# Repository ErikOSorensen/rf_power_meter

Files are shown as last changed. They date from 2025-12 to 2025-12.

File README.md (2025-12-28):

# RF Power Meter

Dual-channel RF power meter using Raspberry Pi Pico with W5500 Ethernet, featuring SCPI control and mDNS discovery.

## Architecture Overview

```
┌─────────────────────────────────────────────────────────────────┐
│                         main.py                                  │
│                    (Application Controller)                      │
│  - Initializes all subsystems                                   │
│  - Runs async task scheduler                                    │
│  - Coordinates sensor reading, display, and network tasks       │
└─────────────────────────────────────────────────────────────────┘
         │              │              │              │
         ▼              ▼              ▼              ▼
┌─────────────┐ ┌─────────────┐ ┌─────────────┐ ┌─────────────┐
│   sensors/  │ │  display/   │ │  network/   │ │    scpi/    │
│             │ │             │ │             │ │             │
│ ADC reading │ │ OLED output │ │ Ethernet &  │ │  Command    │
│ EEPROM cal  │ │ Power bars  │ │ TCP server  │ │  parsing    │
└─────────────┘ └─────────────┘ └─────────────┘ └─────────────┘
```

## Key Features

- **EEPROM-based calibration**: Each sensor module stores its own calibration data in an onboard EEPROM. Calibration travels with the sensor, not the channel.
- **Frequency-dependent calibration**: Store separate offset/slope corrections for each calibration frequency.
- **Hot-swappable sensors**: Sensors are automatically detected at startup via I2C multiplexer.
- **SCPI control**: Standard SCPI commands over TCP port 5025.
- **mDNS discovery**: Find the meter as `rfmeter.local`.

## File Responsibilities

### Core

| File | Purpose |
|---|---|
| `main.py` | Application entry point. Initializes hardware, detects sensors, starts async tasks for sensor reading (50ms), display updates (200ms), TCP server, and mDNS. |
| `config.py` | Central configuration: GPIO pins, I2C addresses, multiplexer settings, network settings, instrument identity. |

### Sensors (`sensors/`)

| File | Purpose |
|---|---|
| `ads1115.py` | Low-level driver for ADS1115 16-bit ADC. Reads power sensor voltage. |
| `tca9548a.py` | TCA9548A I2C multiplexer driver. Selects which sensor's EEPROM is active. |
| `eeprom.py` | AT24C02 EEPROM driver. Reads/writes sensor type, serial number, and calibration data. |
| `calibration.py` | Calibration management. Detects sensors via EEPROM, manages per-frequency calibration, handles voltage-to-dBm conversion. |
| `power_sensor.py` | High-level power measurement. `PowerChannel` handles per-channel reading and averaging. `PowerMeter` manages both channels. |

### Display (`display/`)

| File | Purpose |
|---|---|
| `ssd1306.py` | Low-level driver for SSD1306 OLED displays. |
| `power_display.py` | Power meter UI rendering. Shows power reading, sensor type, bar graph, and IP address. |

### Network (`network/`)

| File | Purpose |
|---|---|
| `w5500.py` | W5500 Ethernet initialization. Configures SPI, handles DHCP. |
| `tcp_server.py` | Async TCP server on port 5025 (SCPI standard). |
| `mdns.py` | Multicast DNS responder. Announces `rfmeter.local`. |

### SCPI (`scpi/`)

| File | Purpose |
|---|---|
| `parser.py` | SCPI command parser. Handles short/long form matching. |
| `commands.py` | SCPI command implementations. |

## Hardware Design

### System Block Diagram

```
                                    ┌─────────────────────────────────┐
                                    │         Main Unit (Pico)        │
┌──────────────┐                    │                                 │
│ Sensor 1     │    Ethernet        │  ┌─────────┐    ┌──────────┐   │
│ ┌─────────┐  │    Cable           │  │TCA9548A │    │ ADS1115  │   │
│ │ RF Det  ├──┼────────────────────┼──┤ I2C Mux ├────┤ ADC #1   │   │
│ │ AD8307  │  │    (Power,I2C,     │  │  0x70   │    │  0x48    │   │
│ └─────────┘  │     Analog)        │  └────┬────┘    └──────────┘   │
│ ┌─────────┐  │                    │       │                        │
│ │ EEPROM  ├──┼────────────────────┼───────┘         ┌──────────┐   │
│ │ AT24C02 │  │                    │  ┌─────────┐    │ ADS1115  │   │
│ │  0x50   │  │                    │  │TCA9548A ├────┤ ADC #2   │   │
│ └─────────┘  │                    │  │ (ch 1)  │    │  0x49    │   │
└──────────────┘                    │  └─────────┘    └──────────┘   │
                                    │                                 │
┌──────────────┐                    │  ┌─────────┐    ┌──────────┐   │
│ Sensor 2     │    Ethernet        │  │TCA9548A │    │  OLED    │   │
│ ┌─────────┐  │    Cable           │  │ (ch 0)  │    │  0x3C    │   │
│ │ RF Det  ├──┼────────────────────┼──┴─────────┘    └──────────┘   │
│ │ AD8317  │  │                    │                                 │
│ └─────────┘  │                    │                 ┌──────────┐   │
│ ┌─────────┐  │                    │                 │  OLED    │   │
│ │ EEPROM  ├──┼────────────────────┼─────────────────┤  0x3D    │   │
│ │ AT24C02 │  │                    │                 └──────────┘   │
│ │  0x50   │  │                    │                                 │
│ └─────────┘  │                    │                 ┌──────────┐   │
└──────────────┘                    │                 │  W5500   │   │
                                    │                 │ Ethernet │   │
                                    │                 └──────────┘   │
                                    └─────────────────────────────────┘
```

### Ethernet Cable Pinout (T-568B)

Sensors connect to the main unit via standard Ethernet cables. This provides a convenient, shielded connection with enough conductors for power, I2C, and analog signals.

| Pin | Wire Color | Function | Notes |
|-----|---|---|---|
| 1 | Orange/White | 3.3V | For EEPROM and 3.3V sensors |
| 2 | Orange | GND | Power ground (shared with 5V return) |
| 3 | Green/White | I2C SDA | To TCA9548A mux |
| 4 | Blue | Analog Output | To ADS1115 input |
| 5 | Blue/White | Analog GND | ADC reference ground |
| 6 | Green | I2C SCL | To TCA9548A mux |
| 7 | Brown/White | 5V | For 5V sensors (AD8317, AD8318) |
| 8 | Brown | Presence Detect | Directly tied to 3.3V on sensor module |

**Power Supply Notes:**
- The EEPROM (AT24C02) always runs on 3.3V
- 3.3V sensors (AD8307, LTC5582): Connect RF detector VCC to pin 1
- 5V sensors (AD8317, AD8318): Connect RF detector VCC to pin 7
- Main unit must provide both 3.3V and 5V rails

**Hot-Swap Detection:**
- Pin 8 is directly connected to 3.3V on each sensor module
- Main unit has internal pull-down on presence detect GPIOs
- When sensor is connected: GPIO reads HIGH (3.3V)
- When sensor is disconnected: GPIO reads LOW (pulled down)
- Rising/falling edge interrupts trigger sensor re-detection

### Main Unit I2C Bus

All I2C devices share a single bus:

| Device | Address | Function |
|---|---|---|
| TCA9548A | 0x70 | I2C multiplexer for sensor EEPROMs |
| ADS1115 #1 | 0x48 | ADC for channel 1 (ADDR→GND) |
| ADS1115 #2 | 0x49 | ADC for channel 2 (ADDR→VDD) |
| OLED #1 | 0x3C | Display for channel 1 |
| OLED #2 | 0x3D | Display for channel 2 |

**Multiplexer Channel Mapping:**
- TCA9548A Channel 0 → Sensor 1 EEPROM
- TCA9548A Channel 1 → Sensor 2 EEPROM

All sensor EEPROMs use address 0x50. The multiplexer isolates them so only one is active at a time.

**Why Two ADS1115 ADCs?**

Each ADS1115 supports 4 single-ended or 2 differential inputs, so a single chip could theoretically handle both channels. However, this design uses one ADC per channel for the following reasons:

1. **Simultaneous sampling**: Both channels can be read at the exact same time with no phase skew or multiplexing delays. This matters when comparing signals between ports or measuring relative power.

2. **Differential measurement**: Each channel uses differential inputs (AIN0-AIN1) with a dedicated analog ground reference per sensor. This provides better noise rejection than single-ended measurements over the Ethernet cable.

3. **Simplicity**: No ADC channel switching logic is needed. Each `PowerChannel` object owns its ADC, making the software straightforward.

4. **Minimal cost impact**: ADS1115 chips are inexpensive (~$1-2), so the added hardware cost is negligible compared to the software complexity savings.

A single-ADC design would require sequential readings with mux switching, introducing timing artifacts when comparing channels.

### Pico Pin Assignments

| Function | Pico Pin | Notes |
|---|---|---|
| I2C SDA | GP0 | I2C0 |
| I2C SCL | GP1 | I2C0 |
| Sensor 1 Detect | GP2 | Pull-down, IRQ on edge |
| Sensor 2 Detect | GP3 | Pull-down, IRQ on edge |
| TCA9548A Reset | GP4 | Active low, external pull-up |
| W5500 SPI MISO | GP16 | SPI0 |
| W5500 CS | GP17 | |
| W5500 SPI SCK | GP18 | SPI0 |
| W5500 SPI MOSI | GP19 | SPI0 |
| W5500 RST | GP20 | |

### Sensor Module Schematic

Each sensor module contains an RF detector chip and an EEPROM. The EEPROM always uses 3.3V, while the RF detector can use either 3.3V or 5V depending on the chip.

**3.3V Sensor (AD8307, LTC5582):**
```
                    ┌─────────────────────────────────────────┐
                    │         Sensor Module (3.3V)            │
   RJ45             │                                         │
  ┌─────┐           │  ┌─────────────┐      ┌─────────────┐  │
  │1 3V3├───┬───────┼──┤ VCC         ├──────┤ VCC         │  │
  │2 GND├───┼───────┼──┤         GND ├──────┤         GND │  │
  │3 SDA├───┼───────┼──┤ SDA  EEPROM │      │ RF Detector │  │
  │4 OUT│◄──┼───────┼──┤     AT24C02 │      │   AD8307    ├──┼── RF IN
  │5 AGND├──┼───────┼──┤ SCL   0x50  │      │             │  │   (SMA)
  │6 SCL├───┼───────┼──┤             │      │         OUT ├──┼─► Pin 4
  │7 5V │   │       │  └─────────────┘      └─────────────┘  │
  │8 DET├───┘       │           (directly tied to 3.3V)      │
  └─────┘           └─────────────────────────────────────────┘
```

**5V Sensor (AD8317, AD8318):**
```
                    ┌─────────────────────────────────────────┐
                    │          Sensor Module (5V)             │
   RJ45             │                                         │
  ┌─────┐           │  ┌─────────────┐      ┌─────────────┐  │
  │1 3V3├───┬───────┼──┤ VCC         │      │         VCC ├──┼─── Pin 7 (5V)
  │2 GND├───┼───────┼──┤         GND ├──────┤         GND │  │
  │3 SDA├───┼───────┼──┤ SDA  EEPROM │      │ RF Detector │  │
  │4 OUT│◄──┼───────┼──┤     AT24C02 │      │   AD8318    ├──┼── RF IN
  │5 AGND├──┼───────┼──┤ SCL   0x50  │      │             │  │   (SMA)
  │6 SCL├───┼───────┼──┤             │      │         OUT ├──┼─► Pin 4
  │7 5V ├───┼───────┼──┼─────────────┼──────┤             │  │
  │8 DET├───┘       │  └─────────────┘      └─────────────┘  │
  └─────┘           │           (directly tied to 3.3V)      │
                    └─────────────────────────────────────────┘
```

**Component List (per sensor module):**
- RF detector IC (AD8307, AD8317, AD8318, LTC5582, etc.)
- AT24C02 EEPROM (256 bytes, I2C address 0x50)
- RJ45 jack
- SMA connector for RF input
- Decoupling capacitors (100nF on each power rail)
- I2C pull-up resistors (2× 4.7kΩ)
- ESD protection (1× ESDAVLC6-2BLY for I2C lines)
- RF detector support components (per datasheet)

**Sensor Supply Voltage Reference:**

| Sensor | Supply | Connect VCC to |
|---|---|---|
| AD8307 | 2.7V - 5.5V | Pin 1 (3.3V) or Pin 7 (5V) |
| AD8317 | 3.0V - 5.5V | Pin 7 (5V) recommended |
| AD8318 | 4.5V - 5.5V | Pin 7 (5V) required |
| LTC5582 | 3.0V - 3.6V | Pin 1 (3.3V) only |

### Main Unit Schematic

The main unit requires both 3.3V (from Pico) and 5V (external) power supplies.

```
  5V DC ────┬──────────────────────────────────────────────────► To RJ45 Pin 7
            │
            │    Raspberry Pi Pico
            │   ┌─────────────────┐
            │   │                 │
     ┌──────┼───┤ GP0 (I2C0 SDA)  │
     │    ┌─┼───┤ GP1 (I2C0 SCL)  │
     │    │ │   │ GP2 (DET1)      ├◄───────────────────────────── Sensor 1 Detect
     │    │ │   │ GP3 (DET2)      ├◄───────────────────────────── Sensor 2 Detect
     │    │ │   │ GP4 (MUX RST)   ├───────────────────┐
     │    │ │   │                 │                   │  TCA9548A RESET
     │    │ │   │ GP16 (SPI MISO) ├────────┐
     │    │ │   │ GP17 (SPI CS)   ├───────┐│
     │    │ │   │ GP18 (SPI SCK)  ├──────┐││
     │    │ │   │ GP19 (SPI MOSI) ├─────┐│││
     │    │ │   │ GP20 (RST)      ├────┐││││
     │    │ │   │                 │    │││││
     │    │ │   │ VSYS ◄──────────┼────┼┼┼┼┼──── 5V DC (powers Pico)
     │    │ │   │ 3V3  ───────────┼─┐  │││││
     │    │ │   │ GND             ├─┼──┼┼┼┼┼─── GND
     │    │ │   └─────────────────┘ │  │││││
     │    │ │                       │  │││││
     │    │ │                       │  │││││    ┌────────────────┐
     │    │ │   ┌───────────────────┼──┼┼┼┼┘    │     W5500      │
     │    │ │   │  ┌────────────────┼──┼┼┼┘     │                │
     │    │ │   │  │  ┌─────────────┼──┼┼┘      │ RST ◄──────────┤
     │    │ │   │  │  │  ┌──────────┼──┼┘       │ CS  ◄──────────┤
     │    │ │   │  │  │  │  ┌───────┼──┘        │ SCK ◄──────────┤
     │    │ │   │  │  │  │  │       │           │ MOSI◄──────────┤
     │    │ │   │  │  │  │  │       │           │ MISO───────────┤
     │    │ │   │  │  │  │  │       └───────────┤ 3V3        GND │
     │    │ │   │  │  │  │  │                   │            ════╪══► Ethernet
     │    │ │   │  │  │  │  │                   └────────────────┘
     │    │ │   │  │  │  │  │
     │    │ │   │  │  │  │  └───────────────────────────────────────┐
     │    │ │   │  │  │  └──────────────────────────────────────┐   │
     │    │ │   │  │  └─────────────────────────────────────┐   │   │
     │    │ │   │  └────────────────────────────────────┐   │   │   │
     │    │ │   └───────────────────────────────────┐   │   │   │   │
     │    │ │                                       │   │   │   │   │
     │    │ │   ┌────────────────────┐              │   │   │   │   │
     │    │ │   │  TCA9548A (0x70)   │◄─────────────┼───┼───┼───┼───┼── GP4 (RST)
     │    │ ├───┤ SDA            SD0 ├──► Sensor 1  │   │   │   │   │
     ├────┼─┼───┤ SCL            SC0 ├──► EEPROM    │   │   │   │   │
     │    │ │   │                SD1 ├──► Sensor 2  │   │   │   │   │
     │    │ │   │                SC1 ├──► EEPROM    │   │   │   │   │
     │    │ │   │ 3V3            GND │              │   │   │   │   │
     │    │ │   └────────────────────┘              │   │   │   │   │
     │    │ │                                       │   │   │   │   │
     │    │ │   ┌─────────────────┐   ┌─────────────────┐   │   │   │
     ├────┼─┼───┤ ADS1115 (0x48)  │   │ ADS1115 (0x49)  │   │   │   │
     │    ├─┼───┤                 │   │                 │   │   │   │
     │    │ │   │ A0 ◄── Sens1 OUT│   │ A0 ◄── Sens2 OUT│   │   │   │
     │    │ │   │ A1 ◄── AGND     │   │ A1 ◄── AGND     │   │   │   │
     │    │ │   └─────────────────┘   └─────────────────┘   │   │   │
     │    │ │                                               │   │   │
     │    │ │   ┌─────────────────┐   ┌─────────────────┐   │   │   │
     ├────┼─┼───┤ OLED (0x3C)     │   │ OLED (0x3D)     │   │   │   │
     │    └─┼───┤ Channel 1       │   │ Channel 2       │   │   │   │
     │      │   └─────────────────┘   └─────────────────┘   │   │   │
     │      │                                               │   │   │
     │      └── I2C SCL ────────────────────────────────────┘   │   │
     └──────── I2C SDA ─────────────────────────────────────────┘   │
                                                                    │
            ┌───────────────────────────────────────────────────────┘
            │
            │   RJ45 Jacks (x2)
            │   ┌─────────────────────────────────────┐
            │   │  Sensor 1          Sensor 2         │
            │   │  ┌───────┐         ┌───────┐        │
            └───┼─►│1: 3V3 │         │1: 3V3 │◄───────┼─── 3V3
   GND ─────────┼─►│2: GND │         │2: GND │◄───────┼─── GND
   I2C SDA ─────┼─►│3: SDA │         │3: SDA │◄───────┼─── (via TCA9548A)
   Sens1 OUT ───┼──│4: OUT │         │4: OUT │────────┼─── Sens2 OUT
   AGND ────────┼─►│5: AGND│         │5: AGND│◄───────┼─── AGND
   I2C SCL ─────┼─►│6: SCL │         │6: SCL │◄───────┼─── (via TCA9548A)
   5V ──────────┼─►│7: 5V  │         │7: 5V  │◄───────┼─── 5V
   GP2 (DET1) ──┼──│8: DET │         │8: DET │────────┼─── GP3 (DET2)
                │  └───────┘         └───────┘        │
                └─────────────────────────────────────┘
```

**Power Supply Requirements:**
- 5V DC input (powers Pico via VSYS, and 5V sensors)
- 3.3V generated by Pico's internal regulator
- Typical current: ~200mA (depends on sensors and Ethernet activity)

## SCPI Command Reference

Connect via TCP port 5025. Commands are terminated with newline (`\n`).

### IEEE 488.2 Common Commands

| Command | Description |
|---|---|
| `*IDN?` | Query instrument identification |
| `*RST` | Reset to default state |
| `*OPC?` | Query operation complete |
| `*CLS` | Clear error queue |

### Measurement Commands

| Command | Description |
|---|---|
| `MEASure:POWer[1\|2]?` | Read power on channel |
| `MEASure:POWer[1\|2]:UNIT <unit>` | Set unit: `DBM`, `DBW`, `MW`, `W` |
| `MEASure:POWer[1\|2]:UNIT?` | Query current unit |
| `MEASure:POWer[1\|2]:AVERage <n>` | Set averaging (1-256) |
| `MEASure:POWer[1\|2]:AVERage?` | Query averaging |
| `MEASure:VOLTage[1\|2]?` | Read raw voltage |

### Frequency Commands

| Command | Description |
|---|---|
| `SENSe:FREQuency[1\|2] <MHz>` | Set operating frequency |
| `SENSe:FREQuency[1\|2]?` | Query current frequency |
| `SENSe:FREQuency[1\|2]:CATalog?` | Query available frequencies |

### External Attenuator Commands

Use these commands when an external attenuator is placed before the sensor. The meter adds the attenuator value to all power readings, so the display and queries report the power level at the attenuator input.

| Command | Description |
|---|---|
| `SENSe:ATTenuation[1\|2] <dB>` | Set external attenuator value |
| `SENSe:ATTenuation[1\|2]?` | Query attenuator value |

**Example:** With a 40 dB attenuator in front of the sensor:
```
SENS:ATT1 40           (set 40 dB attenuator on channel 1)
MEAS:POW1?             → returns +30 (sensor sees -10 dBm, adds 40 dB)
SENS:ATT1?             → 40.0
SENS:ATT1 0            (clear attenuator setting)
```

The display shows "+40dB" indicator when an attenuator is active. The `*RST` command clears attenuator settings to 0.

### Calibration Commands

Calibration is stored **per frequency** on the **sensor EEPROM**.

| Command | Description |
|---|---|
| `CALibrate:POWer[1\|2]:OFFSet <dB>` | Set offset (at current frequency) |
| `CALibrate:POWer[1\|2]:OFFSet?` | Query offset |
| `CALibrate:POWer[1\|2]:SLOPe <factor>` | Set slope correction |
| `CALibrate:POWer[1\|2]:SLOPe?` | Query slope |
| `CALibrate:POWer[1\|2]:SAVE` | Save to sensor EEPROM |
| `CALibrate:POWer[1\|2]:RESTore` | Restore defaults |
| `CALibrate:SENSor[1\|2]:TYPE?` | Query sensor type |

### System Commands

| Command | Description |
|---|---|
| `SYSTem:ERRor?` | Get error from queue |
| `SYSTem:VERSion?` | Query SCPI version |
| `SYSTem:NET:IP?` | Query IP address |
| `SYSTem:NET:MAC?` | Query MAC address |

## Calibration

### How It Works

1. **Sensor identification**: At startup, the main unit reads each sensor's EEPROM to get sensor type, serial number, and calibration frequencies.

2. **Calibration storage**: Each sensor stores its own calibration data. When you move a sensor to a different channel or different meter, the calibration follows.

3. **Per-frequency corrections**: RF detectors have frequency-dependent response. Store separate offset/slope for each calibration frequency.

### EEPROM Data Format

The sensor EEPROM (256 bytes) stores:

| Offset | Size | Content |
|---|---|---|
| 0-3 | 4 | Magic: "RFPM" |
| 4 | 1 | Format version |
| 5 | 1 | Sensor type length |
| 6-13 | 8 | Sensor type string |
| 14 | 1 | Serial number length |
| 15-26 | 12 | Serial number string |
| 27-30 | 4 | Base slope (float) |
| 31-34 | 4 | Base intercept (float) |
| 35 | 1 | Number of frequencies |
| 36-67 | 32 | Frequencies (up to 16 × 2 bytes) |
| 68 | 1 | Number of cal entries |
| 69+ | 10 each | Per-frequency cal (freq + offset + slope) |

### Calibration Procedure

1. **Set frequency:**
   ```
   SENS:FREQ1 100
   ```

2. **Apply reference signal** (e.g., -20 dBm at 100 MHz)

3. **Read and correct:**
   ```
   MEAS:POW1?        → -22.5
   CAL:POW1:OFFS 2.5
   ```

4. **Repeat for other frequencies**

5. **Save to sensor EEPROM:**
   ```
   CAL:POW1:SAVE
   ```

### Programming New Sensors

Use the `SensorEEPROM.format_new_sensor()` method to initialize a new sensor module:

```python
from machine import I2C, Pin
from sensors.eeprom import SensorEEPROM

i2c = I2C(0, sda=Pin(0), scl=Pin(1), freq=400000)
eeprom = SensorEEPROM(i2c, 0x50)

eeprom.format_new_sensor(
    sensor_type="AD8307",
    serial="SN001",
    slope=0.025,           # 25 mV/dB
    intercept=-84.0,       # dBm at 0V
    frequencies=[50, 100, 150, 200, 250, 300, 350, 400, 450, 500]
)
```

## Network Discovery

The instrument announces itself via mDNS:
- Hostname: `rfmeter.local`
- Service: `_scpi-raw._tcp` on port 5025

**Discover:**
```bash
dns-sd -B _scpi-raw._tcp
```

**Connect:**
```bash
nc rfmeter.local 5025
```

## Deployment

1. Copy all files to the Pico maintaining directory structure
2. Program each sensor module's EEPROM with sensor info
3. Connect sensors via Ethernet cables to RJ45 jacks
4. Connect Ethernet to network
5. Power on - sensors auto-detected, DHCP acquired
6. Access via `rfmeter.local:5025`

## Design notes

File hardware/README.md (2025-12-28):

# Hardware Design

KiCad 9 project files for the RF Power Meter.

## Directory Structure

- `main_unit/` - Main unit PCB with Pico, W5500, ADCs, displays, and RJ45 jacks
- `sensor_module/` - Sensor module PCB template (RF detector + EEPROM)

## Design Notes

See the main [README.md](../README.md) for:
- System block diagram
- Ethernet cable pinout (T-568B)
- I2C bus addresses
- Pico pin assignments
- Sensor module schematics (3.3V and 5V variants)

## Analog Input Conditioning

The sensor analog outputs (RJ45 pins 4 and 5) connect to the ADS1115 differential inputs via simple conditioning:

```
                        TVS
                         │
RJ45 Pin 4 (OUT) ────────┼────[100Ω]───┬─── ADS1115 AIN0
                         ┴              │
                        ───          [100nF]
                         │              │
                        GND            GND

                         │
RJ45 Pin 5 (AGND)────────┼────[100Ω]───┬─── ADS1115 AIN1
                         ┴              │
                        ───          [100nF]
                         │              │
                        GND            GND
```

**TVS Diodes (ESD Protection):**
- Part: ESDAVLC6-2BLY (ST, SOT-23-6L, dual line)
- Standoff voltage: 6V (safe for 0-3.3V sensor signals)
- Clamping voltage: ~8V typical
- Capacitance: ~0.45pF per line (very low, negligible signal impact)
- Place close to RJ45 connector to catch ESD before it reaches the PCB

**RC Low-Pass Filter:**
- R: 100Ω per line (keeps ADS1115 source impedance low for proper settling)
- C: 100nF to ground (forms ~1.6kHz low-pass, attenuates RF and HF noise)

No amplification is needed - RF detector outputs (0.2V to 2.5V typical) are well-matched to the ADS1115 at ±4.096V PGA setting, giving ~16,000 counts of resolution across the signal range.

## I2C ESD Protection

The I2C lines (SDA, SCL - RJ45 pins 3 and 6) are exposed to ESD during cable insertion and should be protected:

```
RJ45 Pin 3 (SDA) ────────┬──── TCA9548A SDA
                         ┴
                        ───  TVS (ESDAVLC6-2BLY)
                         │
                        GND

RJ45 Pin 6 (SCL) ────────┬──── TCA9548A SCL
                         ┴
                        ───
                         │
                        GND
```

One ESDAVLC6-2BLY (dual line) protects both SDA and SCL per connector. The ~0.45pF capacitance per line is negligible for 400kHz I2C (bus limit is 400pF).

## I2C Pull-Up Resistors

I2C is open-drain and requires pull-ups. The RP2040's internal pull-ups (~50-80kΩ) are too weak for reliable operation.

**Main I2C bus (near Pico):**

```
3.3V ────┬───────┬────
         │       │
      [2.2kΩ] [2.2kΩ]
         │       │
        SDA     SCL ──── to TCA9548A, ADS1115s, OLEDs
```

**Muxed I2C channels (TCA9548A outputs to RJ45):**

The TCA9548A passes signals through but provides no pull-ups. The Ethernet cable adds capacitance (~50-100pF/m). Pull-ups are needed on both ends:

```
Main Unit:                            Sensor Module:

TCA9548A SD0/SC0 ──┬── RJ45 ══════════ RJ45 ──┬── EEPROM SDA/SCL
                   │                          │
                [10kΩ]                     [4.7kΩ]
                   │                          │
                  3.3V                       3.3V
```

- **Main unit (10kΩ):** Weaker pull-up keeps lines defined when no sensor is connected
- **Sensor module (4.7kΩ):** Stronger pull-up handles cable capacitance
- **Combined (10kΩ ∥ 4.7kΩ ≈ 3.2kΩ):** Adequate for cable length when connected

**Pull-up summary:**

| Location | Value | Quantity | Purpose |
|---|---|---|---|
| Main bus (SDA, SCL) | 2.2kΩ | 2 | Primary pull-up for on-board devices |
| Mux CH0 output (SD0, SC0) | 10kΩ | 2 | Keep lines defined, sensor 1 |
| Mux CH1 output (SD1, SC1) | 10kΩ | 2 | Keep lines defined, sensor 2 |
| Sensor module (SDA, SCL) | 4.7kΩ | 2 per module | Handle cable capacitance |

## ADS1115 ADC Configuration

**ADDR pin (I2C address selection):**

| ADC | Address | ADDR Pin |
|-----|---|---|
| ADS1115 #1 (Channel 1) | 0x48 | GND |
| ADS1115 #2 (Channel 2) | 0x49 | 3.3V |

The ADDR pin must be tied directly to GND or VDD - do not leave floating.

**ALERT/RDY pin:**

The ALERT/RDY pin can signal conversion complete (avoids polling) or comparator alerts. The current software polls the config register, so this pin is unused.

Add a pull-up to keep the open-drain output in a defined state:

```
3.3V
 │
[10kΩ]
 │
ADS1115 ALERT/RDY
```

Do this for both ADS1115 chips. No GPIO connection is needed for the current software.

## TCA9548A I2C Multiplexer Configuration

**Address pins (A0, A1, A2):**

All tied to GND for address 0x70:

| Pin | Connection |
|-----|---|
| A0 | GND |
| A1 | GND |
| A2 | GND |

**RESET pin:**

Connect to GP4 with a pull-up for optional software reset capability:

```
3.3V
 │
[10kΩ]
 │
 ├──── TCA9548A RESET
 │
GP4
```

- Normal operation: GP4 as input (high-Z), RESET held high by pull-up
- Bus recovery: Pull GP4 low to reset mux, clears all channel selections

This allows recovery if the I2C bus gets stuck.

**Unused channels (2-7):**

Leave SDA2-7 and SCL2-7 unconnected. Do NOT tie to ground - if accidentally selected, this would short the I2C bus.

## Presence Detect Conditioning

The presence detect line (RJ45 pin 8) needs a pull-down resistor and ESD protection:

```
RJ45 Pin 8 (DET) ────────┬────────┬──── GP2/GP3
                         ┴        │
                        ───    [10kΩ]
                         │        │
                        GND      GND
                        TVS    Pull-down
```

- **Pull-down (10kΩ):** The RP2040's internal pull-down (~50kΩ) is weak. An external 10kΩ provides better noise immunity when the sensor is disconnected, especially with long cables in an RF environment.
- **TVS:** One ESDAVLC6-2BLY per connector (one line unused, or share between both RJ45 presence detect lines).

## ESD Protection Summary

TVS diodes per RJ45 connector (place close to connector):

| Signals | RJ45 Pins | TVS Package | Notes |
|---|---|---|---|
| Analog OUT + AGND | 4, 5 | 1× ESDAVLC6-2BLY | Before RC filter |
| I2C SDA + SCL | 3, 6 | 1× ESDAVLC6-2BLY | ~0.45pF OK for 400kHz |
| Presence Detect | 8 | 1× ESDAVLC6-2BLY | One line unused |

Total: 6× ESDAVLC6-2BLY for both RJ45 connectors (or 5× if presence detect lines share one package).

## Sensor Module ESD Protection

The sensor module's RJ45 is also exposed when disconnected, and the module is handled frequently. Add TVS protection for the EEPROM I2C lines:

```
        Sensor Module

                 3.3V
                  │
               [4.7kΩ]
                  │
RJ45 Pin 3 ──────┴──────── EEPROM SDA
  (SDA)           │
                 ───
                  ┴  TVS
                 GND

                 3.3V
                  │
               [4.7kΩ]
                  │
RJ45 Pin 6 ──────┴──────── EEPROM SCL
  (SCL)           │
                 ───
                  ┴  TVS (same package)
                 GND
```

- **Part:** 1× ESDAVLC6-2BLY per sensor module (protects both SDA and SCL)
- **Placement:** Close to RJ45 connector
- **Cost:** ~$0.10 per module

The RF detector output typically has internal ESD protection and doesn't require external TVS on the sensor module (the main unit protects this line).

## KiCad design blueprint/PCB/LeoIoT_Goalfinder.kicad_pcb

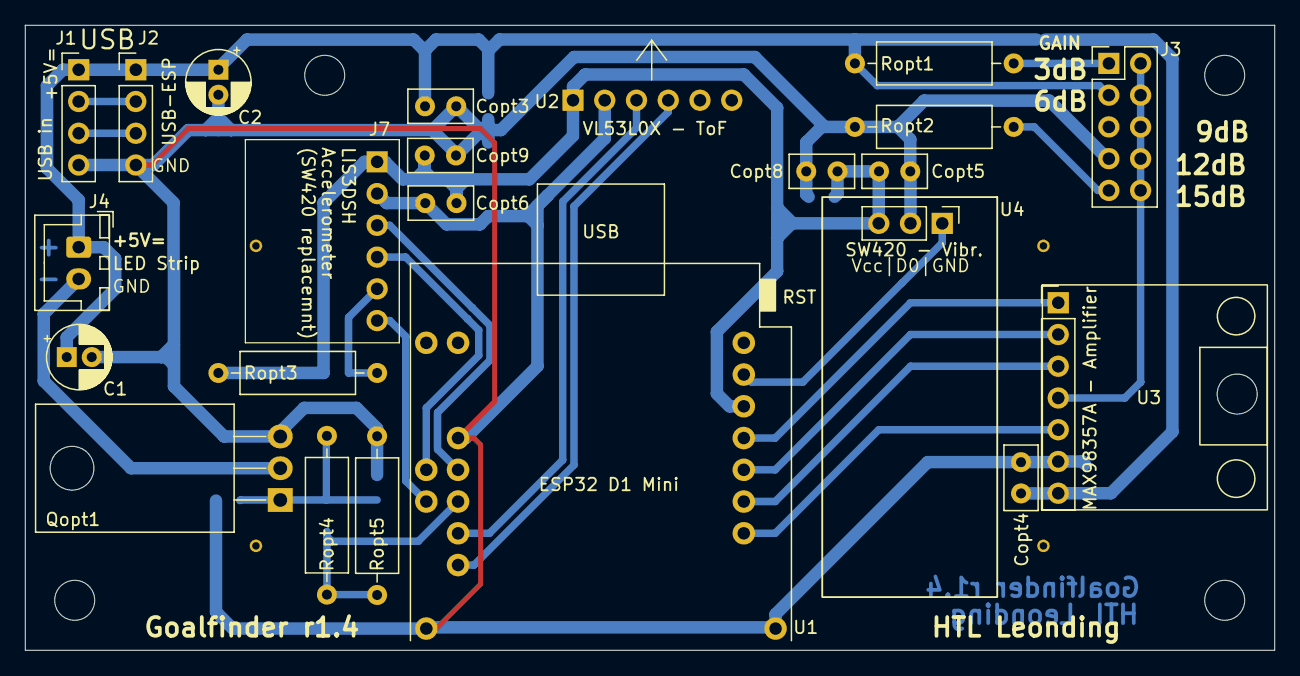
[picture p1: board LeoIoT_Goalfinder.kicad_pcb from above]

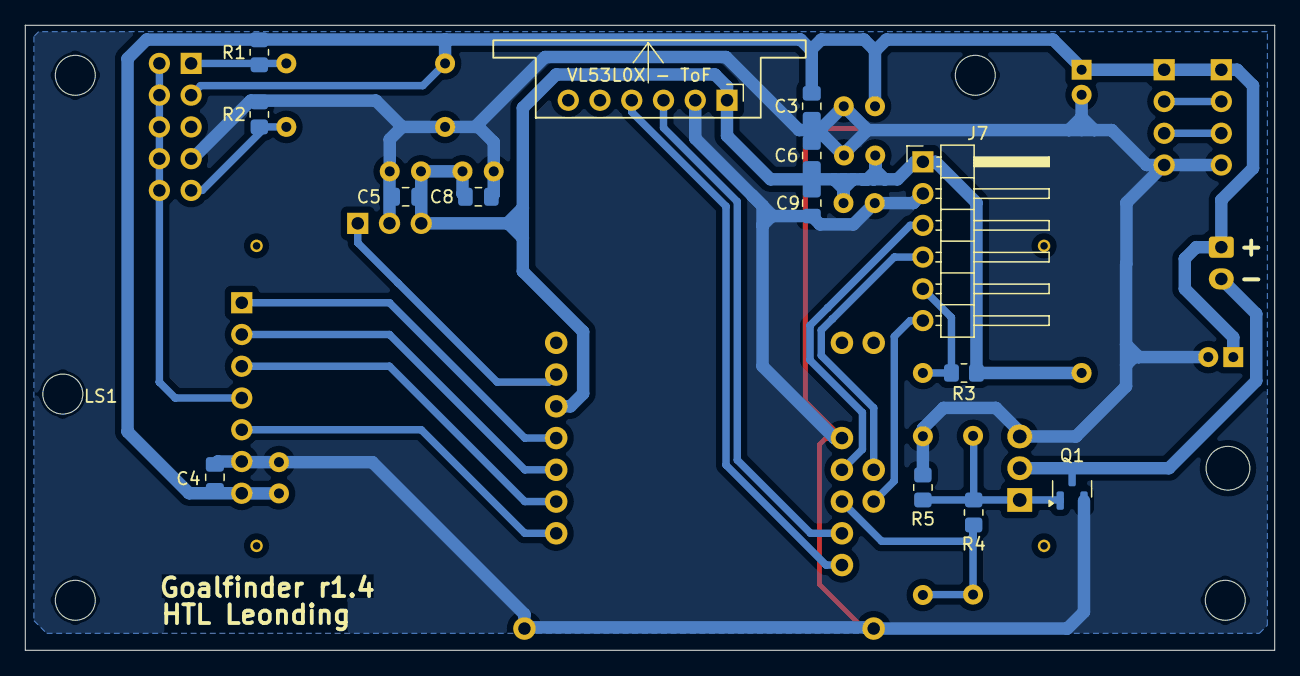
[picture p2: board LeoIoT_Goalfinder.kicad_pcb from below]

Board: 2 copper layers, 100.0 x 50.0 mm, 41 parts (15 on the bottom side), 22 nets.

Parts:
C1: 22µF; CP_Radial_D5.0mm_P2.00mm
C2: 4,7µF; CP_Radial_D5.0mm_P2.00mm
C3, C4, C5, C6, C8, C9: 100nF; C_0805_2012Metric_Pad1.18x1.45mm_HandSolder
Copt3, Copt4, Copt5, Copt6, Copt8, Copt9: 100nF; C_Disc_D5.0mm_W2.5mm_P2.50mm
J1: USB in; PinHeader_1x04_P2.54mm_Vertical
J2: USB-ESP; PinHeader_1x04_P2.54mm_Vertical
J3: GAIN; PinHeader_2x05_P2.54mm_Vertical
J4: LED Strip; JST_XH_B2B-XH-A_1x02_P2.54mm_Vertical
J7: LIS3DH; PinHeader_1x06_P2.54mm_Horizontal
LS1: Speaker; Mono-Enclosed_Speaker_70x30x17mm_onboard
MH1, MH2, MH3, MH3#2, MH4: MountingHole_3.2mm_M3
Q1: IRLML2502; SOT-23
Qopt1: IRLML2502; TO-220-3_Horizontal_TabDown
R1, R2, R3: 100k; R_0805_2012Metric_Pad1.20x1.40mm_HandSolder
R4: 1k; R_0805_2012Metric_Pad1.20x1.40mm_HandSolder
R5: 33k; R_0805_2012Metric_Pad1.20x1.40mm_HandSolder
Ropt1, Ropt2, Ropt3: 100k; R_Axial_DIN0309_L9.0mm_D3.2mm_P12.70mm_Horizontal
Ropt4: 1k; R_Axial_DIN0309_L9.0mm_D3.2mm_P12.70mm_Horizontal
Ropt5: 33k; R_Axial_DIN0309_L9.0mm_D3.2mm_P12.70mm_Horizontal
U1: ESP32 D1 Mini; ESP32_D1_mini
U2: VL53L0X - ToF; VL53L0X_Breakout_Board_vertical_flat
U3: MAX98357A - Amplifier; MAX98357A_Breakout_Board
U4: SW240 - Vcc/D0/GND; SW420_Breakout_Board_Horizontal

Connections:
3V3: C5.1, C6.1, C8.1, C9.1, Copt5.1, Copt6.1, Copt8.1, Copt9.1, J7.1, R3.1, Ropt3.1, U1.16 (3V3), U2.1 (VCC), U4.3
5V: C1.1, C2.1, C3.1, C4.1, Copt3.1, Copt4.1, J1.1, J2.1, J3.3, J4.1, R1.1, Ropt1.1, U3.7 (VDD)
/LED_PWR: J4.2, Q1.3 (D), Qopt1.2 (S)
GND: C1.2, C2.2, C3.2, C4.2, C5.2, C6.2, C8.2, C9.2, Copt3.2, Copt4.2, Copt5.2, Copt6.2, Copt8.2, Copt9.2, J1.4, J2.4, J3.7, J7.2, Q1.2 (S), Qopt1.3 (D), R2.1, R5.2, Ropt2.1, Ropt5.2, U1.1 (GND), U1.22 (GND), U1.33 (GND), U2.2 (GND), U3.6 (GND), U4.2
unnamed: J1.2, J2.2
unnamed: J1.3, J2.3
unnamed: J3.1, R1.2, Ropt1.2
unnamed: J3.9, R2.2, Ropt2.2
unnamed: U1.18 (IO_13/TCK), U4.1
unnamed: U1.27 (IO_21/SDA_1), U2.3 (SDA)
unnamed: U1.25 (IO_22/SCL_1), U2.4 (SCL)
unnamed: J7.3, U1.31 (IO_16/U2_RX)
unnamed: J7.4, U1.32 (IO_04)
unnamed: J7.5, R3.2, Ropt3.2
unnamed: J7.6, U1.30 (IO_12/TDI)
unnamed: Q1.1 (G), Qopt1.1 (G), R4.2, R5.1, Ropt4.2
unnamed: U1.14 (IO_05/SS), U3.1 (LRCLK)
unnamed: R4.1, Ropt4.1, Ropt5.1, U1.29 (IO_17/U2_TXC)
unnamed: U1.8 (IO_18/CLK), U3.5 (~SD_MODE)
unnamed: U1.10 (IO_19/MISO), U3.3 (DIN)
unnamed: U1.12 (IO_23/MOSI), U3.2 (BCLK)
unnamed: J3.2, J3.4, J3.6, J3.8, J3.10, U3.4 (GAIN_SLOT)

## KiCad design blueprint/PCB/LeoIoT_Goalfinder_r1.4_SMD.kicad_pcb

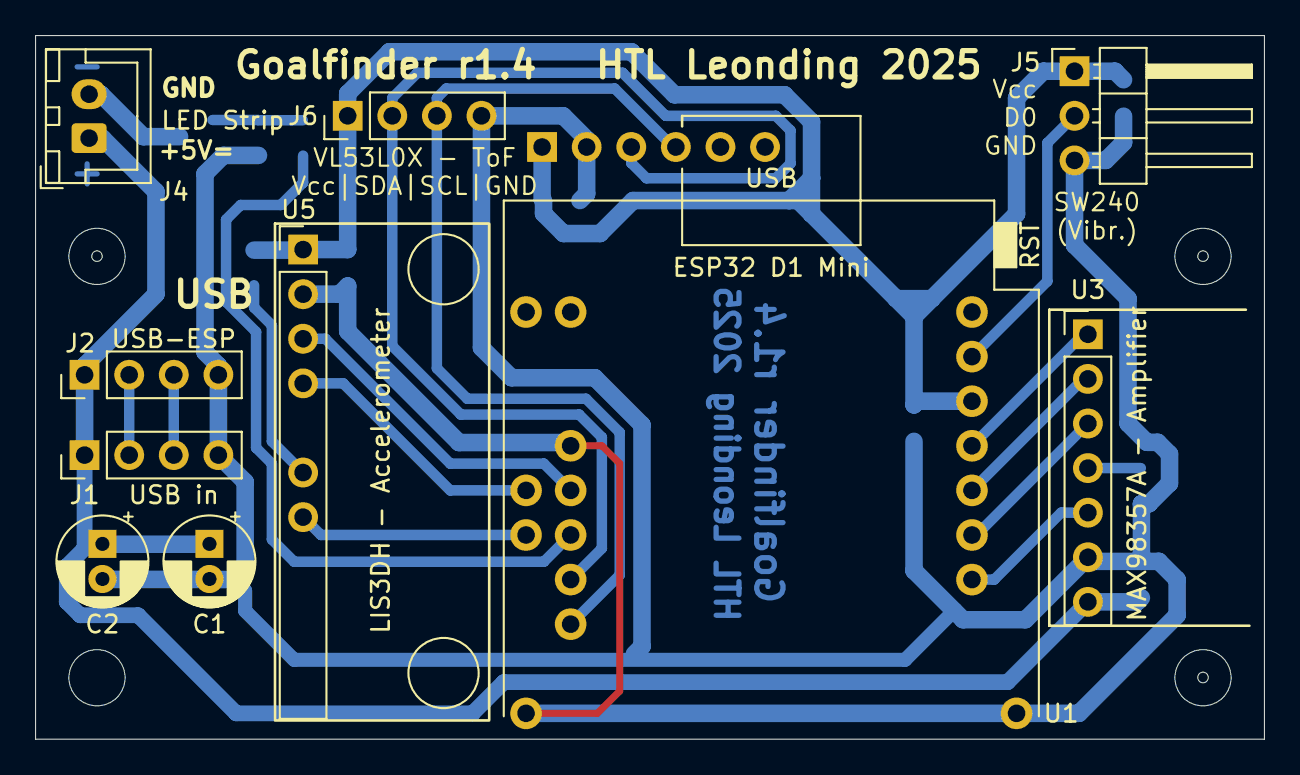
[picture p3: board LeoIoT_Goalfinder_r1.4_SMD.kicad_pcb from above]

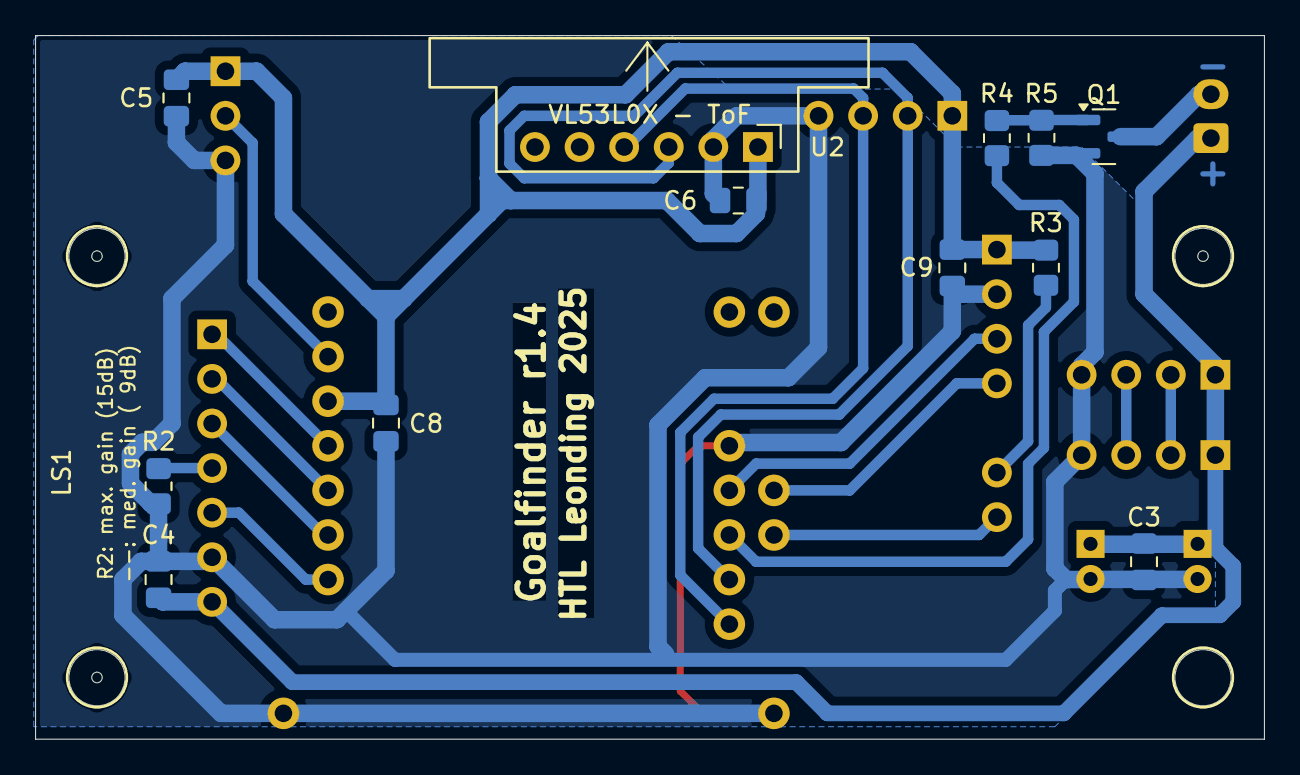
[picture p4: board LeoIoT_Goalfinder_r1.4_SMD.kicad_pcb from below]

Board: 2 copper layers, 70.0 x 40.1 mm, 27 parts (13 on the bottom side), 20 nets.

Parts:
C1: 22µF; CP_Radial_D5.0mm_P2.00mm
C2: 4,7µF; CP_Radial_D5.0mm_P2.00mm
C3, C4, C5, C6, C8, C9: 100nF; C_0805_2012Metric_Pad1.18x1.45mm_HandSolder
J1: USB in; PinHeader_1x04_P2.54mm_Vertical
J2: USB-ESP; PinHeader_1x04_P2.54mm_Vertical
J4: LED Strip; JST_XH_B2B-XH-A_1x02_P2.50mm_Vertical
J5: SW240 - Vcc/D0/GND; PinHeader_1x03_P2.54mm_Horizontal
J6: VL53L0X-ToF Vcc/SDA/SCL/GND; PinHeader_1x04_P2.54mm_Vertical
LS1: Speaker; Mono-Enclosed_Speaker_70x30x17mm_onboard
MH1, MH2, MH3, MH4: MountingHole_3.2mm_M3
Q1: IRLML2502; SOT-23
R2, R3: 100k; R_0805_2012Metric_Pad1.20x1.40mm_HandSolder
R4: 1k; R_0805_2012Metric_Pad1.20x1.40mm_HandSolder
R5: 33k; R_0805_2012Metric_Pad1.20x1.40mm_HandSolder
U1: ESP32 D1 Mini; ESP32_D1_mini
U2: VL53L0X - ToF; VL53L0X_Breakout_Board_vertical_flat
U3: MAX98357A - Amplifier; MAX98357A_Breakout_Board
U5: LIS3DH - Accelerometer; LIS3DH_Breakout_Board

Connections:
3V3: C5.1, C6.1, C8.1, C9.1, J5.1, J6.1, R3.1, U1.16 (3V3), U2.1 (VCC), U5.1 (VCC)
5V: C1.1, C2.1, C3.1, C4.1, J1.1, J2.1, J4.1, U3.7 (VDD)
/LED_PWR: J4.2, Q1.3 (D)
GND: C1.2, C2.2, C3.2, C4.2, C5.2, C6.2, C8.2, C9.2, J1.4, J2.4, J5.3, J6.4, Q1.2 (S), R2.1, R5.2, U1.1 (GND), U1.22 (GND), U1.33 (GND), U2.2 (GND), U3.6 (GND), U5.2 (GND)
unnamed: J1.2, J2.2
unnamed: J1.3, J2.3
unnamed: J5.2, U1.18 (IO_13/TCK)
unnamed: J6.2, U1.27 (IO_21/SDA_1), U2.3 (SDA)
unnamed: J6.3, U1.25 (IO_22/SCL_1), U2.4 (SCL)
unnamed: U1.31 (IO_16/U2_RX), U5.3 (SCL/SPC)
unnamed: U1.32 (IO_04), U5.4 (SDA/SDI/SDO)
unnamed: R3.2, U5.6 (CS)
unnamed: U1.30 (IO_12/TDI), U5.7 (INT1)
unnamed: Q1.1 (G), R4.2, R5.1
unnamed: U1.14 (IO_05/SS), U3.1 (LRCLK)
unnamed: R4.1, U1.29 (IO_17/U2_TXC)
unnamed: U1.8 (IO_18/CLK), U3.5 (~SD_MODE)
unnamed: U1.10 (IO_19/MISO), U3.3 (DIN)
unnamed: U1.12 (IO_23/MOSI), U3.2 (BCLK)
unnamed: R2.2, U3.4 (GAIN_SLOT)

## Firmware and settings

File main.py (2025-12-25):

# RF Power Meter - Main Entry Point
# Dual-channel RF power meter with SCPI interface

import uasyncio as asyncio
from machine import I2C, Pin
import time

import config
from sensors.power_sensor import PowerMeter
from display.power_display import DisplayManager
from network.w5500 import get_network, init_network_async
from network.tcp_server import TCPServer
from network.mdns import MDNSResponder
from scpi.commands import create_scpi_handler


class RFPowerMeter:
    """Main RF Power Meter application."""

    def __init__(self):
        """Initialize power meter components."""
        self.i2c = None
        self.meter = None
        self.display_mgr = None
        self.network = None
        self.tcp_server = None
        self.mdns = None
        self.scpi_handler = None
        self.running = False

    def init_hardware(self):
        """Initialize I2C bus and hardware."""
        print("Initializing hardware...")

        # Initialize I2C bus
        self.i2c = I2C(
            config.I2C_ID,
            sda=Pin(config.I2C_SDA),
            scl=Pin(config.I2C_SCL),
            freq=config.I2C_FREQ
        )

        # Scan I2C bus
        devices = self.i2c.scan()
        print("I2C devices found:", [hex(d) for d in devices])

        # Initialize power meter
        self.meter = PowerMeter(self.i2c)
        print("Power meter initialized")

        # Detect sensors via EEPROM
        print("Detecting sensors...")
        sensors = self.meter.detect_sensors()
        for ch, sensor_type in sensors.items():
            if sensor_type:
                serial = self.meter.cal_mgr.get_sensor_serial(ch)
                print("  Channel {}: {} (S/N: {})".format(ch, sensor_type, serial))
            else:
                print("  Channel {}: No sensor".format(ch))

        # Initialize displays
        self.display_mgr = DisplayManager(self.i2c)
        self.display_mgr.show_startup()
        print("Displays initialized")

        time.sleep(1)  # Show startup screen briefly

    async def init_network(self):
        """Initialize network connection."""
        print("Initializing network...")

        self.network = get_network()
        self.network.init()

        # Show DHCP status on displays
        self.display_mgr.set_ip_address(None)

        # Connect with DHCP
        ip = await init_network_async(use_dhcp=config.USE_DHCP)

        if ip:
            print("Network connected: {}".format(ip))
            self.display_mgr.set_ip_address(ip)

            # Initialize mDNS
            self.mdns = MDNSResponder(config.MDNS_HOSTNAME, ip)
            print("mDNS hostname: {}.local".format(config.MDNS_HOSTNAME))
        else:
            print("Network connection failed")
            self.display_mgr.show_error("Network failed")

        return ip

    def init_scpi(self):
        """Initialize SCPI command handler."""
        self.scpi_handler = create_scpi_handler(self.meter, self.network)
        print("SCPI handler initialized")

    async def sensor_task(self):
        """Task for continuous sensor reading."""
        print("Sensor task started")

        while self.running:
            try:
                # Check for hot-swap events (sensor connect/disconnect)
                self.meter.check_presence_changes()

                for channel in self.meter.channels.values():
                    channel.read_power()

                await asyncio.sleep_ms(config.SENSOR_READ_MS)

            except Exception as e:
                print("Sensor task error:", e)
                await asyncio.sleep_ms(1000)

    async def display_task(self):
        """Task for display updates."""
        print("Display task started")

        while self.running:
            try:
                self.display_mgr.update_all(self.meter)
                await asyncio.sleep_ms(config.DISPLAY_UPDATE_MS)

            except Exception as e:
                print("Display task error:", e)
                await asyncio.sleep_ms(1000)

    async def scpi_server_task(self):
        """Task for SCPI TCP server."""
        if self.network.get_ip() is None:
            print("SCPI server: No network")
            return

        print("Starting SCPI server on port {}".format(config.SCPI_PORT))
        self.tcp_server = TCPServer(self.scpi_handler, config.SCPI_PORT)
        await self.tcp_server.start()

        # Keep running while active
        while self.running:
            await asyncio.sleep_ms(1000)

    async def mdns_task(self):
        """Task for mDNS responder."""
        if self.mdns is None:
            print("mDNS: Not configured")
            return

        # Send initial announcement
        await asyncio.sleep_ms(100)
        self.mdns.announce()

        # Run responder
        await self.mdns.run()

    async def main(self):
        """Main async entry point."""
        print("\n=== RF Power Meter ===")
        print("Model: {} v{}".format(config.MODEL, config.VERSION))
        print()

        # Initialize hardware
        self.init_hardware()

        # Initialize network
        await self.init_network()

        # Initialize SCPI
        self.init_scpi()

        # Start all tasks
        self.running = True

        tasks = [
            asyncio.create_task(self.sensor_task()),
            asyncio.create_task(self.display_task()),
        ]

        # Add network tasks if connected
        if self.network and self.network.get_ip():
            tasks.append(asyncio.create_task(self.scpi_server_task()))
            if self.mdns:
                tasks.append(asyncio.create_task(self.mdns_task()))

        print("\nSystem ready")
        print("SCPI: {}:{}".format(
            self.network.get_ip() if self.network else "N/A",
            config.SCPI_PORT
        ))
        print()

        # Wait for all tasks
        try:
            await asyncio.gather(*tasks)
        except asyncio.CancelledError:
            pass

    def run(self):
        """Run the power meter."""
        try:
            asyncio.run(self.main())
        except KeyboardInterrupt:
            print("\nShutting down...")
            self.running = False


# Entry point
def main():
    """Application entry point."""
    app = RFPowerMeter()
    app.run()


if __name__ == "__main__":
    main()

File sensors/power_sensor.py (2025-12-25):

# Power Sensor Reading and Management
# Handles ADC reading, averaging, and power calculation

import uasyncio as asyncio
from machine import Pin
from .ads1115 import ADS1115, PGA_4_096V
from .calibration import CalibrationManager
import config

# Power units
UNIT_DBM = "DBM"
UNIT_DBW = "DBW"
UNIT_MW = "MW"
UNIT_W = "W"


def dbm_to_mw(dbm):
    """Convert dBm to milliwatts."""
    return 10.0 ** (dbm / 10.0)


def dbm_to_w(dbm):
    """Convert dBm to watts."""
    return 10.0 ** ((dbm - 30.0) / 10.0)


def dbm_to_dbw(dbm):
    """Convert dBm to dBW."""
    return dbm - 30.0


class PowerChannel:
    """Represents a single power measurement channel."""

    def __init__(self, channel_num, adc, calibration_mgr):
        """
        Initialize power channel.

        Args:
            channel_num: Channel number (1 or 2)
            adc: ADS1115 instance for this channel
            calibration_mgr: CalibrationManager instance
        """
        self.channel_num = channel_num
        self.adc = adc
        self.cal_mgr = calibration_mgr
        self.averaging = config.ADC_SAMPLES_DEFAULT
        self.unit = UNIT_DBM

        # External attenuator offset (dB, added to measured power)
        self.attenuator = 0.0

        # Current readings
        self.power_voltage = 0.0
        self.power_dbm = None

        # Averaging buffer
        self._samples = []

    @property
    def sensor_type(self):
        """Get detected sensor type."""
        return self.cal_mgr.get_sensor_type(self.channel_num)

    @property
    def sensor_serial(self):
        """Get sensor serial number."""
        return self.cal_mgr.get_sensor_serial(self.channel_num)

    def get_frequency(self):
        """Get current operating frequency in MHz."""
        return self.cal_mgr.get_frequency(self.channel_num)

    def set_frequency(self, freq_mhz):
        """
        Set operating frequency in MHz.

        Args:
            freq_mhz: Frequency in MHz

        Returns:
            Actual frequency set (may snap to nearest valid)
        """
        return self.cal_mgr.set_frequency(self.channel_num, freq_mhz)

    def get_frequencies(self):
        """Get list of valid calibration frequencies for this sensor."""
        return self.cal_mgr.get_frequencies(self.channel_num)

    def read_voltage(self):
        """Read power sensor voltage from ADC."""
        self.power_voltage = self.adc.read_power_voltage()
        return self.power_voltage

    def read_power(self):
        """
        Read and calculate power with averaging.

        Returns:
            Power in dBm or None if sensor not detected
        """
        # Read voltage
        self.power_voltage = self.adc.read_power_voltage()

        # Update averaging buffer
        self._samples.append(self.power_voltage)
        if len(self._samples) > self.averaging:
            self._samples.pop(0)

        # Calculate average voltage
        avg_voltage = sum(self._samples) / len(self._samples)

        # Convert to dBm
        self.power_dbm = self.cal_mgr.voltage_to_dbm(
            self.channel_num, avg_voltage
        )
        return self.power_dbm

    def get_power(self, unit=None, include_attenuator=True):
        """
        Get power in specified unit.

        Args:
            unit: Power unit (DBM, DBW, MW, W) or None for channel default
            include_attenuator: If True, add attenuator offset to reading

        Returns:
            Tuple of (value, unit_string) or (None, unit) if no reading
        """
        if self.power_dbm is None:
            return None, unit or self.unit

        # Apply attenuator offset (add dB to get input power)
        corrected_dbm = self.power_dbm
        if include_attenuator:
            corrected_dbm += self.attenuator

        target_unit = unit or self.unit

        if target_unit == UNIT_DBM:
            return corrected_dbm, "dBm"
        elif target_unit == UNIT_DBW:
            return dbm_to_dbw(corrected_dbm), "dBW"
        elif target_unit == UNIT_MW:
            return dbm_to_mw(corrected_dbm), "mW"
        elif target_unit == UNIT_W:
            return dbm_to_w(corrected_dbm), "W"
        else:
            return corrected_dbm, "dBm"

    def set_averaging(self, samples):
        """Set number of samples for averaging."""
        self.averaging = max(1, min(256, samples))
        self._samples = []  # Clear buffer on change

    def set_unit(self, unit):
        """Set default power unit."""
        if unit in [UNIT_DBM, UNIT_DBW, UNIT_MW, UNIT_W]:
            self.unit = unit

    def clear_averaging(self):
        """Clear averaging buffer."""
        self._samples = []

    def set_attenuator(self, value_db):
        """
        Set external attenuator value.

        Args:
            value_db: Attenuator value in dB (positive number)
                      This is added to measured power to get input power.
                      Example: 40 dB attenuator, sensor reads -10 dBm,
                               reported power is +30 dBm.
        """
        self.attenuator = float(value_db)

    def get_attenuator(self):
        """Get current attenuator value in dB."""
        return self.attenuator
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

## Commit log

2025-12-24 First cut at software, after a bit of vibe-coding with Claude Code (Opus).
2025-12-25 Added 3.3V to a 'presence pin' do detect hot-swapping of sensor heads.
    [config.py, main.py, power_sensor.py]
2025-12-25 Add analog input conditioning notes with ESD protection and RC filtering
    Documents the recommended circuit for connecting sensor outputs to the
    ADS1115 ADC inputs: TVS diodes (PESD5V0L2BT-Q) for ESD protection and
    100Ω/100nF RC low-pass filter for noise rejection.
2025-12-25 Add I2C and presence detect protection to hardware notes
    - I2C lines: TVS protection (PESD5V0L2BT-Q) for SDA/SCL
    - Presence detect: 10kΩ external pull-down + TVS protection
    - Summary table of all ESD protection components per RJ45
2025-12-25 Add I2C pull-up resistor recommendations
    - Main bus: 2.2kΩ pull-ups near Pico
    - Mux outputs: 10kΩ to keep lines defined when no sensor
    - Sensor module: 4.7kΩ to handle cable capacitance
2025-12-25 Add sensor module ESD protection and update component list
    - Add PESD5V0L2BT-Q for I2C lines on sensor module
    - Update sensor module component list with TVS and pull-ups
2025-12-25 Fix sensor module I2C schematic diagram
    Corrected ASCII art to show pull-ups from SDA/SCL to 3.3V,
    not in series with the signal path.
2025-12-26 Add TCA9548A configuration (address pins, reset, unused channels)
    - Address pins A0-A2 tied to GND for 0x70
    - RESET connected to GP4 with 10kΩ pull-up for bus recovery
    - Document that unused channels should be left floating (not grounded)
    - Update main schematic, pin assignments, and config.py
    [config.py]
2025-12-26 Add ADS1115 ADDR pin configuration
    - ADS1115 #1: ADDR to GND for address 0x48
    - ADS1115 #2: ADDR to VDD for address 0x49
2025-12-27 Add ADS1115 ALERT/RDY pin configuration
    Pull-up to 3.3V via 10kΩ - not connected to GPIO since software uses polling.
2025-12-28 Change TVS diode from PESD5V0L2BT-Q to ESDAVLC6-2BLY
    ST part with lower capacitance (~0.45pF vs ~1pF) and better availability.
2025-12-28 Started schematics and layout. Not finished!
    [AD8307.kicad_pcb, AD8307.kicad_sch, main_board.kicad_pcb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]
2026-10-25 Move ADC into sensor heads, add SSD1322 display, one I2C bus per head
    Architecture:
    - Each sensor head now carries the ADS1115 ADC, an MCP9808 temperature
    sensor, the EEPROM and its own LDOs. The Ethernet cable carries only
    8V, I2C and a presence-detect tie to ground.
    - Drop the TCA9548A multiplexer: head 1 is on Pico I2C0 (GP0/GP1), head
    2 on I2C1 (GP2/GP3). Presence detect moves to GP4/GP5, active low.
    - Replace the two I2C SSD1306 OLEDs with one 256x64 SSD1322 grayscale
    OLED on SPI1 (GP10/GP11, CS GP13, D/C GP14, RST GP15), showing both
    channels side by side.
    - Main unit power: 12V input, LM317M set to 8V for the head rail, 1A 5V
    buck for the W5500-EVB-Pico, SOT-223 3.3V LDO f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
2026-10-25 Add front panel rotary encoder for frequency and attenuator entry
    - ui/encoder.py: interrupt-driven quadrature decoder (one step per
    detent) and push button; relies on hardware debouncing
    - ui/front_panel.py: short press cycles CH1 freq -> CH1 atten -> CH2
    freq -> CH2 atten -> measurement view; rotation steps frequency
    through the head's calibration list and the attenuator in whole dB
    from 0 to 60; 5 s idle timeout; remote lock, always unlocked at boot
    - SCPI: SYSTem:KLOCk ON|OFF and query; frequency/attenuator writes and
    *RST cancel a manual edit in progress
    - Display: frequency and attenuator on a per-channel info line with the
    active field inverted; temperature moves to the he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
2026-10-25 Interpolate calibration between frequency points for SCPI-set frequencies
    - SENSe:FREQuency accepts any (fractional) frequency inside the head's
    calibrated range; offset and slope are linearly interpolated between
    the bracketing calibration points. Out-of-range values are clamped to
    the nearest end point with error -222.
    - Calibration writes (CAL:POW:OFFS/SLOP) land on the calibration point
    nearest the operating frequency and queue error -100 naming the point
    when it differs; queries return the interpolated value.
    - Front panel still steps through calibration points only; from an
    interpolated frequency the first click moves to the neighbouring
    point in the direction of rotation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
2026-11-07 Split firmware into src/, add B612 bitmap fonts and new display layout
    - Move all Pico code into src/, which mirrors the Pico's filesystem
    root. Rename the network package to net so it no longer shadows
    MicroPython's built-in network module.
    - Add tools/ for desktop-only code. tools/fonts/make_fonts.py renders
    B612 (fonts/, OFL) into 4-bit antialiased bitmap fonts with tabular
    digits: Bold 30 px, Regular 12 px and 9 px.
    - Add display/bitmapfont.py to draw them with framebuf blit + palette.
    - Move screen drawing into display/layout.py (hardware-free): one row
    per channel with name, sensor tag, frequency/pad, a right-aligned
    reading with two decimals, and the unit. IP and hostname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
2026-11-07 Fix RJ45 wiring in README diagrams
    - Sensor head diagram: pin 3 goes to SDA and pin 4 to SCL (they were
    swapped), and the GND returns on pins 5, 6 and 7 join the GND bus.
    - Presence detect diagram: pin 8 goes to GP4/GP5, not GP2/GP3.
2026-11-07 Remove stray 5V line into ADS1115 AIN0 in sensor head diagram
    The 5V detector rail ran down to the detector OUT/AIN0 node. It now
    ends as a labelled LDO output; the detector VCC pin already reads
    "3V3 or 5V rail".
2026-11-07 AD8307 sensor head schematic: work in progress
    Three more resistors, the +5V symbol replaced by VCC, two fewer +3V3
    symbols. Project file upgraded to the current KiCad format.
2026-11-07 Working on sensor head design.
2026-11-07 Main board schematic: remove on-board ADS1115s and TCA9548A, start new power and OLED sections
2026-11-07 Use Amphenol's LED-less RJHSE-5380 STEP model for the main board RJ45 footprint
2026-11-08 AD8307 head: LP2985 regulator, 4-layer layout outline with RJ45 notch, centred connectors, Würth RJ45 3D model; main board: power tree, OLED header, encoder debounce
2026-11-08 Sync READMEs with the schematics: head power and EEPROM as drawn, main unit power tree, OLED header pinout, encoder RC values, schematic status
2026-11-08 AD8307 head: silkscreen I2C address table and RJ45 pinout, re-annotated references, power net class with neck-down rule, GND pour on B.Cu; READMEs updated to match
2026-11-08 AD8307 head: add six test points (detector output, +3V3, VCC, SDA, SCL, GND); note them in the READMEs
